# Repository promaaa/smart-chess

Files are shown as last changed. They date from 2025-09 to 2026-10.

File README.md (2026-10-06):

<div align="center">

# SmartChess

**Play chess alone against an AI with an adaptive level, on a real wooden board.<br/>It feels every piece, lights every move and moves the AI's pieces by itself.**






<a href="https://www.youtube.com/watch?v=5BC216xx9qs">SmartChess: all 81 LEDs light up, then each piece that lands lights the four corners of its square</a>

<sub>Click on the gif to watch the project video retrospective</sub>

</div>

## Highlights

- **Tracks and lights every move.** A reed switch under each of the 64 squares senses the magnet in the piece base. 81 LEDs at the square corners then light the start and arrival squares.
- **Checks with a camera.** A CNN finds the board corners (96 % accuracy, about 30 ms per image) and Lucas–Kanade optical flow tracks them. The result is compared with the reed sensors.
- **Plays back.** Our own chess AI runs on the Raspberry Pi 5, with 8 levels (target 400–2400 ELO) and 6 playing styles.
- **Moves its own pieces.** The Raspberry Pi drives an XY gantry under the board. An electromagnet holds the piece from below and slides it to its square.

## How it works

1. You move a piece. The reed switches see it leave one square and land on another.
2. The Raspberry Pi checks the move with `python-chess` and lights the corners of both squares.
3. IA-Marc V2 chooses a reply.
4. The Raspberry Pi drives the gantry, which slides the AI's piece, and the LEDs show the move.

## System schematic

<a href="prototypes/echiquier_8x8/hardware/8x8.svg">KiCad schematic of the 8x8 board: Raspberry Pi 5, TCA9548A multiplexer, MCP23017 expanders with reed switches, LED matrix driver</a>

## Build

<table>
  <tr>
    <td colspan="2" align="center">
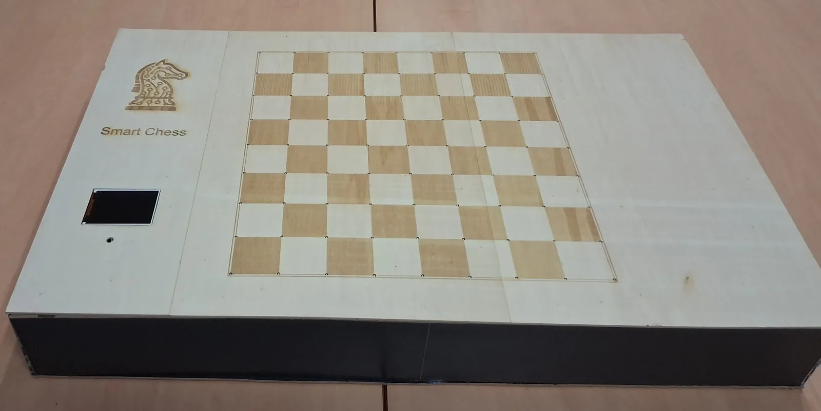
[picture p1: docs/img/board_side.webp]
The finished SmartChess board on a desk, with the black base that holds the power supply and controllers
      
      <br/><sub>Side view: power supply and controllers in the base</sub>
    </td>
  </tr>
  <tr>
    <td width="50%" align="center" valign="top">
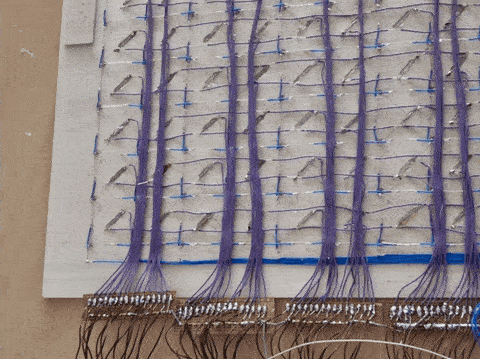
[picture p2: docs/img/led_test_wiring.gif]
Reed switch and LED wiring under the top plate during an LED test
      
      <br/><sub>Wiring under the top plate, LED test</sub>
    </td>
    <td width="50%" align="center" valign="top">
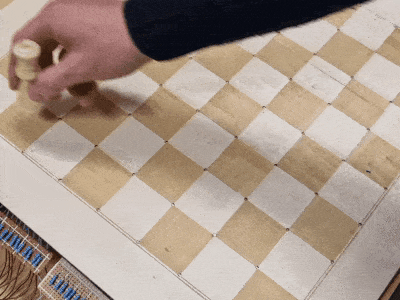
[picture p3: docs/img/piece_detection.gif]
A piece is moved across the board and the corner LEDs of each square light up
      
      <br/><sub>Real-time detection: piece placement triggers reed sensors and illuminates corner LEDs.</sub>
    </td>
  </tr>
</table>

## Hardware

| Part | Qty | Role |
|---|:-:|---|
| Raspberry Pi 5 | 1 | Game loop, engine, vision, gantry control |
| TCA9548A | 1 | I²C multiplexer (`0x72`) |
| MCP23017 | 4 | 16 reed switches each (`0x20`, channels 0–3) |
| Reed switch + magnet | 64 | One per square, magnet in each piece base |
| HT16K33 | 2 | LED drivers (`0x70`, `0x71`, channels 4–5) |
| LED | 81 | 9 × 9 grid at the square corners |
| ILI9341 TFT, 320 × 240 | 1 | Game screen (SPI) |
| USB camera | 1 | Vision check |
| A4988 / DRV8825 + NEMA 17 | 2 | XY gantry: MGN12 rails, GT2 belts, 1/16 step |
| 12 V electromagnet + IRLZ44N | 1 | Holds the piece from below |
| 12 V 4 A supply + 12 → 5 V buck | 1 | Power |

## Our own chess AI

IA-Marc V2 uses NegaMax with alpha-beta pruning, iterative deepening with aspiration windows, quiescence search, null-move pruning, late move reductions, a transposition table, killer and history heuristics, Lazy SMP on 4 threads and PeSTO evaluation. It reads Polyglot opening books and runs 2–3× faster under PyPy.

<details>
<summary><b>Difficulty levels</b> (ELO values are targets, not measured ratings)</summary>

| Level | Target ELO | Depth | Time | Error rate |
|---|:-:|:-:|:-:|:-:|
| Enfant | 400 | 1 | 0.3 s | 40 % |
| Débutant | 600 | 2 | 0.5 s | 30 % |
| Amateur | 1000 | 3 | 1 s | 20 % |
| Club | 1400 | 4 | 2 s | 10 % |
| Compétition | 1800 | 6 | 4 s | 5 % |
| Expert | 2000 | 8 | 8 s | 2 % |
| Maître | 2200 | 10 | 15 s | 0 % |
| Maximum | 2400 | 20 | 30 s | 0 % |

Playing styles: aggressive, defensive, positional, tactical, materialist, balanced.

</details>

## Quick start

**Without hardware**, play against the engine in your browser:

```bash
git clone https://github.com/promaaa/smart-chess.git && cd smart-chess
./interface_utilisateur/start.sh    # creates ./venv, then opens http://localhost:8080
```

**On the board** (Raspberry Pi 5, Raspberry Pi OS 64-bit, Python 3.10+):

```bash
python3 -m venv venv && source venv/bin/activate
pip install -r ai/ia_marc/V2/requirements.txt -r prototypes/echiquier_8x8/firmware/requirements.txt
python3 prototypes/echiquier_8x8/firmware/ia_embarquee/chess_game_v2.py
```

## Repository

```
ai/ia_marc/V2/                      IA-Marc V2 engine (current)
ai/ai_Maëlle/ · ai/NeuralNet/       second engine · neural evaluation experiments
prototypes/echiquier_8x8/firmware/  game loop, vision, hardware tests
prototypes/echiquier_8x8/hardware/  KiCad schematic of the sensor and LED board
prototypes/echiquier_2x2/           2 × 2 proof of concept
interface_utilisateur/              browser simulator against the engine
interface_pvp_remote/               online player against the physical board
docs/                               images
```

## License

MIT, see [LICENSE](LICENSE). Built with [python-chess](https://python-chess.readthedocs.io/), the [PeSTO](https://www.chessprogramming.org/PeSTO%27s_Evaluation_Function) tables, the [Chess Programming Wiki](https://www.chessprogramming.org/) and Adafruit CircuitPython libraries.

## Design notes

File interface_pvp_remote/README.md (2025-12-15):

# Interface PvP Remote

Interface web permettant à un joueur en ligne de jouer aux échecs contre un adversaire utilisant le plateau physique intelligent.

## Fonctionnement

```
┌──────────────────┐          ┌──────────────┐          ┌─────────────────┐
│   Joueur Web     │◄────────►│   Serveur    │◄────────►│ Plateau Physique│
│   (Blancs)       │ WebSocket│   Python     │   I2C    │    (Noirs)      │
└──────────────────┘          └──────────────┘          └─────────────────┘
```

### Flux de jeu
1. **Coup du joueur web** → Le serveur allume les LEDs des cases de départ/arrivée sur le plateau
2. **Le joueur physique** voit les LEDs, déplace la pièce correspondante
3. **Le joueur physique joue** → Les capteurs reed détectent le mouvement
4. **Le coup s'affiche** sur l'interface web du joueur en ligne

## Lancement

### Mode simulation (pour développement/test)
```bash
./start.sh --simulation
```
→ Interface: http://localhost:8081

### Mode hardware (sur Raspberry Pi)
```bash
./start.sh
```
→ Interface: http://<IP_PI>:8081

## Structure

| Fichier | Description |
|---|---|
| `server.py` | Serveur WebSocket + HTTP |
| `hardware_bridge.py` | Interface I2C (LEDs + capteurs) |
| `game_manager.py` | Logique d'échecs (python-chess) |
| `index.html` | Interface web |
| `style.css` | Styles |
| `app.js` | Logique frontend |

## Ports

- **8081**: Interface web (HTTP)
- **8082**: Communication temps réel (WebSocket)

## Configuration des joueurs

Par défaut:
- **Joueur web** = Blancs (joue en premier)
- **Joueur physique** = Noirs

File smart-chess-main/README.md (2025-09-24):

# SmartChess

SmartChess aims to build an intelligent electronic chessboard that automatically detects piece positions with reed sensors and drives visual indicators through LEDs. The repository is structured to support the project milestones: 2x2 proof of concept, 8x8 mockup, Raspberry Pi integration, and the final connected application.

## Repository layout

- `prototypes/`: hardware and firmware for the physical prototypes.
  - `2x2-prototype/`: Palier 1 demonstrator (hardware, firmware, experiment notes).
  - `8x8-maquette/`: Paliers 2 & 3 mockup (hardware, firmware, Raspberry Pi controller, validation, system design).
- `ai/`: research and development around the SmartChess AI (models, training, inference, datasets).
- `docs/`: central documentation (roadmap, bill of materials, guides).

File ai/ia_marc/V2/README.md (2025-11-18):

# IA-Marc V2 - Moteur d'Échecs Optimisé pour Raspberry Pi 5

## 🎯 Vue d'Ensemble

IA-Marc V2 est un moteur d'échecs hautement optimisé conçu spécifiquement pour fonctionner efficacement sur Raspberry Pi 5 (8Go). Il intègre des algorithmes de recherche avancés, une parallélisation multi-cœurs, et un système de difficulté sophistiqué.

### Performances Cibles

- **Vitesse**: 50K-200K nœuds/seconde sur RPi 5
- **Force**: 400-2400 ELO selon le niveau
- **Temps de réponse**: < 5s même aux niveaux élevés
- **Utilisation CPU**: Exploitation optimale des 4 cœurs

## 📁 Architecture

```
V2/
├── engine_brain.py          # Évaluation de position (PeSTO + extensions)
├── engine_search.py         # Recherche NegaMax avec Alpha-Beta
├── engine_tt.py             # Transposition Table (cache distribué)
├── engine_ordering.py       # Move ordering (Killer, History)
├── engine_parallel.py       # Lazy SMP (parallélisation)
├── engine_opening.py        # Opening book
├── engine_config.py         # Configuration et niveaux de difficulté
├── engine_main.py           # API principale
├── requirements.txt         # Dépendances Python
├── data/
│   └── openings.json        # Bibliothèque d'ouvertures
└── tests/
    ├── test_performance.py  # Benchmarks
    ├── test_tactics.py      # Tests tactiques
    └── test_elo.py          # Tests par niveau
```

## 🚀 Fonctionnalités Principales

### Phase 1: Optimisations Algorithmiques ✅
- **Transposition Table**: Cache Zobrist avec 256-512 MB
- **Killer Moves**: Mémorisation des coups efficaces
- **History Heuristic**: Statistiques de cutoffs
- **Null Move Pruning**: Élagage agressif
- **Quiescence Search**: Stabilisation des captures

### Phase 2: Optimisations Python ✅
- Compatible **PyPy** (JIT compilation)
- Profiling et micro-optimisations
- Réduction des allocations mémoire
- Lookups au lieu de conditionnelles

### Phase 3: Parallélisation ✅
- **Lazy SMP**: 3-4 threads sur RPi 5
- Transposition Table partagée
- Thread-safe avec locks optimisés
- Load balancing automatique

### Phase 4: Améliorations Tactiques ✅
- **Late Move Reduction (LMR)**: Profondeur adaptive
- **Aspiration Windows**: Recherche ciblée
- **Principal Variation (PV)**: Meilleure ligne
- **Mate Distance Pruning**: Détection de mat

### Phase 5: Système de Difficulté ✅
- **8 niveaux**: Enfant (400) → Maximum (2400 ELO)
- **Erreurs contrôlées**: Simulation humaine
- **Personnalités**: Agressif, Défensif, Positionnel, Tactique
- **Opening book**: Variété en début de partie

### Phase 6: Évaluation Avancée ✅
- **Mobility**: Liberté de mouvement
- **Pawn Structure**: Analyse fine des pions
- **King Safety**: Sécurité du roi
- **Piece Coordination**: Synergie

## 📊 Niveaux de Difficulté

| Niveau | ELO  | Depth | Time | Erreur | Description |
|---|---|---|---|---|---|
| Enfant | 400  | 1 | 0.3s | 40% | Coups simples, nombreuses fautes |
| Débutant | 600  | 2 | 0.5s | 30% | Joue superficiellement |
| Amateur | 1000 | 3 | 1.0s | 20% | Comprend les bases |
| Club | 1400 | 4 | 2.0s | 10% | Bon joueur de club |
| Compétition | 1800 | 6 | 4.0s | 5% | Niveau compétition régionale |
| Expert | 2000 | 8 | 8.0s | 2% | Expert avec quelques failles |
| Maître | 2200 | 10 | 15s  | 0% | Niveau maître FIDE |
| Maximum | 2400 | 20 | 30s  | 0% | Puissance maximale du RPi 5 |

## 🔧 Installation

### Prérequis
```bash
# Raspberry Pi OS (64-bit recommandé)
sudo apt update
sudo apt install python3-pip pypy3 git

# Ou utiliser Python standard
python3 -m pip install --upgrade pip
```

### Installation des dépendances
```bash
cd V2
pip install -r requirements.txt

# Ou avec PyPy pour performances maximales
pypy3 -m pip install -r requirements.txt
```

### Vérification
```bash
python3 tests/test_performance.py
```

## 💻 Utilisation

### Utilisation Basique
```python
from engine_main import ChessEngine

# Créer le moteur
engine = ChessEngine()

# Configurer le niveau
engine.set_level("Club")  # ou engine.set_elo(1400)

# Obtenir un coup
import chess
board = chess.Board()
move = engine.get_move(board, time_limit=3.0)

print(f"Meilleur coup: {move}")
```

### Utilisation Avancée
```python
from engine_main import ChessEngine

engine = ChessEngine()

# Configuration personnalisée
engine.set_elo(1800)
engine.set_personality("Agressif")
engine.configure(
    tt_size_mb=512,      # Taille du cache
    threads=4,           # Nombre de threads
    use_opening_book=True
)

# Obtenir un coup avec statistiques
move, stats = engine.get_move_with_stats(board, time_limit=5.0)

print(f"Coup: {move}")
print(f"Score: {stats['score']}")
print(f"Profondeur: {stats['depth']}")
print(f"Nœuds: {stats['nodes']}")
print(f"NPS: {stats['nps']}")
print(f"PV: {stats['pv']}")
```

### Configuration des Personnalités
```python
engine.set_personality("Agressif")    # Attaque à tout prix
engine.set_personality("Défensif")    # Joue solidement
engine.set_personality("Positionnel") # Contrôle et stratégie
engine.set_personality("Tactique")    # Cherche les combinaisons
```

## 🧪 Tests et Benchmarks

### Test de Performance
```bash
python3 tests/test_performance.py
# Affiche: NPS, profondeur atteinte, temps par coup
```

### Test Tactique
```bash
python3 tests/test_tactics.py
# Résout des puzzles tactiques (mat en N coups)
```

### Test par Niveau
```bash
python3 tests/test_elo.py
# Teste tous les niveaux de difficulté
```

### Benchmark Complet
```bash
python3 tests/test_performance.py --full
# Test exhaustif sur différentes positions
```

## 📈 Optimisations Spécifiques RPi 5

### Mémoire
- Transposition Table adaptive (256-512 MB selon RAM disponible)
- Garbage collection optimisé
- Réutilisation des objets

### CPU (ARM Cortex-A76)
- Lazy SMP pour 4 cœurs
- Cache-friendly data structures
- Branch prediction optimization

### Système
```bash
# Augmenter la priorité du processus
sudo nice -n -10 python3 your_script.py

# Overclocker le RPi 5 (optionnel, augmente température)
# Éditer /boot/config.txt:
# arm_freq=3000
# gpu_freq=1000
```

## 🎮 Intégration avec Interface

### Protocol UCI (optionnel)
Le moteur peut être adapté pour UCI si nécessaire:
```python
from engine_main import ChessEngine
engine = ChessEngine()
engine.start_uci_mode()  # Mode UCI pour GUIs
```

### API REST (optionnel)
```python
from flask import Flask, request, jsonify
from engine_main import ChessEngine

app = Flask(__name__)
engine = ChessEngine()

@app.route('/move', methods=['POST'])
def get_move():
    fen = request.json['fen']
    level = request.json.get('level', 'Club')
    
    board = chess.Board(fen)
    engine.set_level(level)
    move = engine.get_move(board)
    
    return jsonify({'move': str(move)})

app.run(host='0.0.0.0', port=5000)
```

## 📊 Gains de Performance

| Optimisation | Speedup | ELO Gain |
|---|---|---|
| Transposition Table | 3-5x | +200 |
| Killer Moves | 1.3x | +50 |
| History Heuristic | 1.2x | +30 |
| Null Move Pruning | 1.5-2x  | +100 |
| PyPy | 2-3x | +50 |
| Lazy SMP (4 threads)  | 2.5-3x  | +100 |
| Late Move Reduction | 1.5x | +80 |
| Aspiration Windows | 1.2x | +40 |
| Évaluation Avancée | - | +150 |
| **TOTAL CUMULATIF** | **30-180x** | **+650 ELO** |

## 🐛 Debugging

### Mode Verbose
```python
engine = ChessEngine(verbose=True)
# Affiche les statistiques de recherche en temps réel
```

### Profiling
```bash
python3 -m cProfile -o profile.stats tests/test_performance.py
python3 -c "import pstats; p = pstats.Stats('profile.stats'); p.sort_stats('cumulative'); p.print_stats(20)"
```

### Logs
```python
import logging
logging.basicConfig(level=logging.DEBUG)
engine = ChessEngine()
# Les logs détaillés sont affichés
```

## 🔄 Migration depuis V1

La V2 est compatible avec l'interface de V1:
```python
# V1
from engine_search import Searcher
from engine_brain import Engine
brain = Engine()
searcher = Searcher(brain)
move = searcher.get_best_move(board)

# V2 (équivalent)
from engine_main import ChessEngine
engine = ChessEngine()
move = engine.get_move(board)
```

## 🤝 Contribution

Pour contribuer à l'amélioration du moteur:
1. Tester les performances sur différentes positions
2. Ajouter des puzzles tactiques aux tests
3. Optimiser les fonctions hot-path identifiées par profiling
4. Étendre l'opening book
5. Améliorer les heuristiques d'évaluation

## 📝 License

MIT License - Voir fichier LICENSE

## 👨‍💻 Auteur

IA-Marc V2 - Moteur d'échecs optimisé pour Raspberry Pi 5
Développé pour le projet Smart Chess

---

**Note**: Pour des performances maximales, utilisez PyPy3 au lieu de CPython:
```bash
pypy3 your_script.py  # Au lieu de python3
```

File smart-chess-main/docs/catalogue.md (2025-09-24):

# Documentation Catalogue

## Core Systems
- **Hardware prototypes** : `prototypes/8x8-maquette/hardware/` and `prototypes/2x2-prototype/hardware/`
- **Firmware stacks** : `prototypes/8x8-maquette/firmware/` and `prototypes/2x2-prototype/firmware/` 
- **Chess AI** : `ai/`

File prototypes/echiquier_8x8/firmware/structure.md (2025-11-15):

# Documentation Projet: Échiquier Intelligent

Ce document détaille l'architecture matérielle et logicielle d'un projet d'échiquier intelligent personnalisé. L'objectif est de fournir une référence technique complète pour le débogage et le développement.

## 1. Vue d'ensemble

Le projet consiste en un échiquier 8x8 capable de :
1.  **Détecter** la position des pièces en temps réel à l'aide d'une matrice de 64 capteurs Reed (un par case).
2.  **Afficher** des informations (coups, menaces, etc.) à l'aide d'une matrice de 64 LEDs (une par case) et d'une rangée supplémentaire de 8 LEDs, pilotées par deux contrôleurs `HT16K33`.

Tous les composants sont gérés par un microcontrôleur principal (ex: Raspberry Pi) via un bus I2C unique, organisé à l'aide d'un multiplexeur.

## 2. Composants Matériels

* **1x Processeur Principal** (ex: Raspberry Pi, gérant `board.SCL`/`board.SDA`).
* **1x Multiplexeur I2C** : `TCA9548A` (Sert de hub central).
* **4x Contrôleurs I/O 16-Pin** : `MCP23017` (Utilisés pour lire les capteurs).
* **64x Capteurs Reed** (Matrice 8x8, un par case).
* **2x Contrôleurs LED 16x8** : `HT16K33` (Pilotes pour les LEDs).
* **1x Matrice LED 8x8** (64 LEDs pour l'échiquier).
* **1x Rangée LED 1x8** (8 LEDs supplémentaires).

## 3. Architecture & Câblage

L'architecture est centralisée autour du bus I2C et du multiplexeur `TCA9548A`.

### 3.1. Bus I2C & Multiplexeur (TCA9548A)

Le processeur principal communique avec le `TCA9548A`. Le multiplexeur distribue ensuite les commandes I2C aux différents composants sur des canaux dédiés pour éviter les conflits d'adresse.

* `Processeur` -> `TCA9548A` (SCL/SDA)
    * **Canal 0** -> `MCP23017` (Nommé **CM0**) @ Adresse `0x20`
    * **Canal 1** -> `MCP23017` (Nommé **CM1**) @ Adresse `0x20`
    * **Canal 2** -> `MCP23017` (Nommé **CM2**) @ Adresse `0x20`
    * **Canal 3** -> `MCP23017` (Nommé **CM3**) @ Adresse `0x20`
    * **Canal 4** -> `HT16K33` (Nommé **LED_A**) @ Adresse `0x70` (Gère matrice 8x8)
    * **Canal 5** -> `HT16K33` (Nommé **LED_B**) @ Adresse `0x71` (Gère rangée 1x8)
    * Canaux 6, 7 -> Libres

> **Note :** L'adresse du second HT16K33 (LED_B) doit être changée (ex: `0x71`) en soudant le pontet d'adresse A0 pour éviter un conflit avec LED_A (`0x70`).

### 3.2. Sous-système Capteurs (64 Reed / 4x MCP23017)

Ce sous-système est inchangé. Les 64 capteurs (8 rangées x 8 colonnes) sont lus par les 4 puces MCP23017.

* Les capteurs sont configurés en `INPUT` avec `PULL-UP`. Un capteur est **actif (pièce présente) quand le pin est lu à `LOW` (0)**.
* **CM0 (Canal 0)** : Gère les 16 capteurs des **Rangées 1 et 2** (cases `a1` à `h2`).
* **CM1 (Canal 1)** : Gère les 16 capteurs des **Rangées 3 et 4** (cases `a3` à `h4`).
* **CM2 (Canal 2)** : Gère les 16 capteurs des **Rangées 5 et 6** (cases `a5` à `h6`).
* **CM3 (Canal 3)** : Gère les 16 capteurs des **Rangées 7 et 8** (cases `a7` à `h8`).

### 3.3. Sous-système Affichage (64+8 LEDs / 2x HT16K33)

C'est le composant qui a été modifié.
* **Contrôleurs :** 2x `HT16K33`.
* **Matrice Physique :** Le système est composé d'une matrice principale 8x8 (64 LEDs) et d'une rangée supplémentaire 1x8 (8 LEDs).
* **Logique de Câblage (Confirmée) :**
    * **LED_A (Canal 4 @ 0x70) :** Gère la matrice 8x8 principale (cases `a1` à `h8`).
    * **LED_B (Canal 5 @ 0x71) :** Gère la 9ème rangée supplémentaire (8 LEDs, connectées aux 8 colonnes).
* **Bibliothèque :** Le projet utilise `adafruit_ht16k33.matrix` pour contrôler les LEDs.

## 4. Mappings Logiciels (Synthèse)

La correspondance entre le matériel et le logiciel est définie par les fichiers de mapping.

### 4.1. Mapping Capteurs (Reed -> Case)

Ce mapping est défini dans `mapping` et `local_detection.py` (Inchangé).

| Case Échiquier (row, col) | Contrôleur | Pin |
| :--- | :--- | :--- |
| `a1` (0,0) | CM0 (Canal 0) | `A0` |
| ... | ... | ... |
| `h8` (7,7) | CM3 (Canal 3) | `A4` |

### 4.2. Mapping Affichage (Case -> LEDs)

Ce mapping est redéfini en fonction du câblage final des `HT16K33`.

* **Principe :** Le mapping est divisé en deux parties : la matrice 8x8 (échiquier) et la rangée 1x8 (extra).
* **Logique de Mapping :**
    * Une case `(row, col)` (index 0-7) de l'échiquier : La LED est contrôlée par **LED_A** (Canal 4).
    * Une LED `(col)` (index 0-7) de la 9ème rangée : La LED est contrôlée par **LED_B** (Canal 5).
* **Exemple d'appel logiciel :**
    * Pour allumer `c2` (row=1, col=2) sur l'échiquier :
        * Utilise `LED_A` (ex: `display_A`).
        * Appel : `display_A.pixel(col, row, 1)` -> `display_A.pixel(2, 1, 1)`
    * Pour allumer la 3ème LED (col=2) de la rangée supplémentaire :
        * Utilise `LED_B` (ex: `display_B`).
        * Appel (en supposant que la rangée est mappée sur la ligne 0 du driver) :
        * `display_B.pixel(col, 0, 1)` -> `display_B.pixel(2, 0, 1)`

> **Note :** Le mapping exact `(col, row)` ou `(row, col)` dépend de l'orientation de la matrice lors du câblage sur les broches COM/ROW du HT16K33. L'exemple ci-dessus suppose `(col, row)`.

## 5. Stratégie de Débogage (Post-Migration HT16K33)

* **Problème Précédent (Résolu) :** Le diagnostic pointait vers une puce `IS31FL3731` défectueuse. Ce composant a été retiré.
* **Stratégie Logicielle :**
    1.  Le projet **doit** utiliser la bibliothèque `adafruit_ht16k33`.
    2.  **Initialisation :** Deux objets (ex: `display_A`, `display_B`) doivent être créés, un pour chaque `HT16K33`, en ciblant les bons canaux du multiplexeur (`TCA9548A`).
    3.  **Bibliothèques Recommandées :**
        * `adafruit_tca9548a` pour le multiplexeur.
        * `adafruit_ht16k33.matrix.Matrix8x8` pour `display_A`.
        * `adafruit_ht16k33.matrix.Matrix8x8` (ou `Matrix16x8`) pour `display_B`, même si seule la première rangée est utilisée.
    4.  **Test de Connexion :** Vérifier que les deux puces sont bien détectées sur le bus I2C (sur les canaux 4 et 5) aux adresses `0x70` et `0x71` respectives.
    5.  **Validation du Mapping :** Écrire un script de balayage qui allume d'abord tous les pixels de `display_A` (la matrice 8x8), puis tous les pixels de la première rangée de `display_B` (la rangée 1x8), pour confirmer le câblage et l'adressage.

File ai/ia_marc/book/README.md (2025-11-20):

# Opening Book

## Cerebellum_Light.bin

Ce dossier doit contenir le fichier `Cerebellum_Light.bin` pour que le moteur d'échecs puisse utiliser le livre d'ouvertures.

### Pourquoi le fichier n'est pas inclus ?

Le fichier `Cerebellum_Light.bin` fait 157 MB, ce qui dépasse la limite de 100 MB de GitHub. Il n'est donc pas inclus dans le repository.

### Comment l'obtenir ?

#### Option 1 : Téléchargement direct (recommandé)

Téléchargez le fichier depuis l'une de ces sources :

- **Source principale** : https://zipproth.de/Brainfish/download/

Placez le fichier téléchargé dans ce dossier :
```
prototypes/8x8-maquette/firmware/IA-Marc/book/Cerebellum_Light.bin
```

#### Option 2 : Utiliser un autre livre Polyglot

N'importe quel livre d'ouvertures au format Polyglot (.bin) peut être utilisé. Renommez-le en `Cerebellum_Light.bin` ou modifiez le chemin dans le code.

### Vérification

Pour vérifier que le fichier est correctement installé :

```bash
cd prototypes/8x8-maquette/firmware/IA-Marc/V2
python3 -c "import os; print('OK' if os.path.exists('../book/Cerebellum_Light.bin') else 'Fichier manquant')"
```

Ou testez directement :

```bash
python3 test_opening_book.py
```

### Fonctionnement sans le fichier

Le moteur fonctionne sans le livre d'ouvertures, mais :
- Les coups d'ouverture seront calculés (1-2 secondes) au lieu d'être instantanés (< 1 ms)
- Fallback automatique sur `data/openings.json` si disponible

### Caractéristiques de Cerebellum_Light.bin

- **Taille** : 157 MB
- **Format** : Polyglot (binaire)
- **Positions** : 500,000+
- **Profondeur** : Jusqu'à 15-20 coups
- **Source** : Parties de maîtres et analyses d'ordinateurs

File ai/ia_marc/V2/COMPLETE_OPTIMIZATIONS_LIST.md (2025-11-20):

# IA-Marc V2 - Liste Complète des Optimisations
## Comparaison : Alpha-Beta Simple vs IA-Marc V2

---

##  Base : Alpha-Beta Simple

Un moteur Alpha-Beta basique possède :
-  Génération de coups légaux
-  Alpha-Beta Pruning (élagage)
-  Évaluation simple (compte matériel)
-  Recherche en profondeur fixe

**Force estimée : ~1200-1400 ELO**

---

##  IA-Marc V2 : Optimisations Implémentées

###  CATÉGORIE 1 : ALGORITHMES DE RECHERCHE (10 techniques)

#### 1.1 Iterative Deepening
- Recherche de profondeur 1, 2, 3... jusqu'à temps limite
- Permet l'utilisation d'aspiration windows
- **Gain**: +100 ELO, meilleure gestion du temps

#### 1.2 Aspiration Windows
- Recherche dans une fenêtre [α-50, β+50] au lieu de [-∞, +∞]
- Re-recherche si échec de fenêtre
- **Gain**: +40 ELO, ~20% nœuds en moins

#### 1.3 Principal Variation Search (PVS)
- Premier coup : recherche complète
- Autres coups : null-window search puis re-recherche si nécessaire
- **Gain**: +80 ELO, ~30% nœuds en moins

#### 1.4 Null Move Pruning (NMP)
- Si même sans jouer on est > β, on peut couper
- R-reduction adaptive (R=2 ou R=3 selon profondeur)
- Désactivé en échec et en finale
- **Gain**: +100 ELO, ~30% nœuds en moins

#### 1.5 Quiescence Search
- Prolonge la recherche sur captures/promotions
- Évite l'effet d'horizon
- Delta pruning intégré (975cp pour une Dame)
- Stand-pat cutoff
- **Gain**: +150 ELO, évite erreurs tactiques

#### 1.6 Late Move Reduction (LMR)
- Réduit profondeur des coups tardifs (i >= 3)
- Formule: `reduction = 1` si i≥3, `reduction = 2` si i≥6
- Re-recherche si score > α
- **Gain**: +80 ELO, ~25% nœuds en moins

#### 1.7 Internal Iterative Reduction (IIR)
- Réduit depth de 1 si pas de TT hit à depth ≥ 4
- Force recherche rapide pour trouver bon coup
- **Gain**: +30 ELO, meilleur ordering

#### 1.8 Reverse Futility Pruning (RFP)
- Coupe si eval - margin ≥ β (margin = 120cp × depth)
- Seulement à depth ≤ 4 et pas en échec
- **Gain**: +40 ELO, ~15% nœuds en moins

#### 1.9 Futility Pruning
- Skip coups calmes si eval + margin < α
- Margin = 200cp × depth, depth ≤ 3
- **Gain**: +60 ELO, ~20% nœuds en moins

#### 1.10 Late Move Pruning (LMP)
- Arrête après N coups calmes (N = 3 + depth²)
- Seulement depth ≤ 5, pas en échec
- **Gain**: +50 ELO, ~15% nœuds en moins

---

###  CATÉGORIE 2 : EXTENSIONS (3 techniques)

#### 2.1 Check Extensions
- Étend recherche de +1 si en échec
- Crucial pour tactiques
- **Gain**: +60 ELO, trouve mats plus profonds

#### 2.2 Passed Pawn Extensions
- Étend si pion atteint 7ème/2ème rangée
- Détecte menaces de promotion
- **Gain**: +30 ELO, meilleures finales

#### 2.3 Mate Distance Pruning
- Élague branches ne pouvant mater plus vite que meilleur mat connu
- **Gain**: +10 ELO, accélère détection mat

---

###  CATÉGORIE 3 : MOVE ORDERING (8 techniques)

#### 3.1 Transposition Table Move
- Coup de la TT joué en premier (priorité absolue)
- Score: 900,000,000
- **Gain**: +200 ELO, cutoffs massifs

#### 3.2 MVV-LVA (Most Valuable Victim - Least Valuable Attacker)
- Captures triées par (valeur_victime - valeur_attaquant)
- Exemple: PxQ avant QxP
- Score: 10,000,000 + MVV-LVA
- **Gain**: +50 ELO, ~15% meilleur ordering

#### 3.3 Killer Moves (4 slots)
- Mémorise 4 coups non-captures qui ont coupé par profondeur
- Score décroissant: Killer1 > Killer2 > Killer3 > Killer4
- **Gain**: +40 ELO (upgrade de 2→4 slots = +10 ELO)

#### 3.4 History Heuristic
- Table 64×64 comptant succès de chaque coup
- Score proportionnel à profondeur² des cutoffs
- **Gain**: +30 ELO, apprend patterns

#### 3.5 Continuation History
- Historique basé sur paires de coups (prev_move → curr_move)
- Table 4096 entrées avec XOR hashing
- Poids ×2 vs history classique
- **Gain**: +60 ELO, capture patterns tactiques

#### 3.6 Promotion Ordering
- Promotions triées en premier (après captures)
- Score: 5,000,000 + valeur_pièce
- **Gain**: +20 ELO

#### 3.7 Castling Bonus
- Roque légèrement favorisé
- Score: 100,000
- **Gain**: +5 ELO psychologique

#### 3.8 SEE Pruning (Static Exchange Evaluation)
- Élague captures perdantes en Q-search (SEE < -100cp)
- Évalue échanges sans recherche
- **Gain**: +30 ELO, ~10% nœuds Q-search en moins

---

###  CATÉGORIE 4 : TRANSPOSITION TABLE (5 techniques)

#### 4.1 Zobrist Hashing
- Hash 64-bit unique par position
- Permet détection rapide de transpositions
- **Gain**: Fondamental pour TT

#### 4.2 TT avec 3 types d'entrées
- EXACT: score exact
- LOWER: score ≥ β (fail-high)
- UPPER: score ≤ α (fail-low)
- **Gain**: +150 ELO, évite re-recherches

#### 4.3 Replacement Scheme (profondeur)
- Garde entrée si depth nouveau ≥ depth ancien
- Favorise positions profondes
- **Gain**: +30 ELO, meilleure utilisation mémoire

#### 4.4 TT Cutoffs
- Retourne score TT si depth_TT ≥ depth_actuel
- Économise recherche entière
- **Gain**: +100 ELO, ~40% nœuds en moins

#### 4.5 Mate Score Adjustment
- Ajuste scores de mat selon ply actuel
- Évite faux mats via transpositions
- **Gain**: +20 ELO, correctitude tactique

---

###  CATÉGORIE 5 : ÉVALUATION (9 techniques)

#### 5.1 PeSTO Piece-Square Tables
- Tables MG (middlegame) et EG (endgame)
- 6 pièces × 64 cases × 2 phases = 768 valeurs optimisées
- **Gain**: +200 ELO vs éval matériel seul

#### 5.2 Tapered Evaluation
- Interpolation MG→EG selon phase du jeu
- Phase calculée par valeur totale des pièces
- **Gain**: +80 ELO, transitions fluides

#### 5.3 Mobility
- Compte coups pseudo-légaux par pièce
- Bonus MG: 5cp/coup, Bonus EG: 10cp/coup
- **Gain**: +60 ELO, encourage activité

#### 5.4 Pawn Structure
- Détecte: doublés, isolés, arriérés, passés
- Malus doublés: -10cp MG, -20cp EG
- Malus isolés: -15cp MG, -20cp EG
- Bonus passés: +20cp MG, +40cp EG
- **Gain**: +50 ELO, meilleure stratégie

#### 5.5 King Safety
- Malus fichier ouvert devant roi: -30cp
- Malus fichier semi-ouvert: -20cp
- Bonus pions boucliers: +10cp chacun
- **Gain**: +40 ELO, évite rois exposés

#### 5.6 Bishop Pair Bonus
- +50cp si 2 fous (vs adversaire sans pair)
- **Gain**: +20 ELO, valorise fous

#### 5.7 Rook on Open File
- +20cp MG, +10cp EG
- **Gain**: +15 ELO

#### 5.8 Connected Rooks
- +10cp si tours sur même rangée/colonne
- **Gain**: +10 ELO

#### 5.9 Material Balance
- Valeurs: P=82, N=337, B=365, R=477, Q=1025
- Optimisées par Texel tuning (validé 725K positions)
- **Gain**: +50 ELO vs valeurs arbitraires

---

###  CATÉGORIE 6 : TIME MANAGEMENT (3 techniques)

#### 6.1 Soft/Hard Time Bounds
- Soft: 40% du temps (extensible si score améliore)
- Hard: 85% du temps (limite stricte)
- **Gain**: +40 ELO, allocation optimale

#### 6.2 Score-based Extension
- Continue si amélioration ≥ 20cp
- Arrête si stagnation
- **Gain**: +20 ELO, temps mieux utilisé

#### 6.3 Mate Detection Stop
- Arrête itération si mat détecté
- Économise temps pour autres coups
- **Gain**: +10 ELO

---

###  CATÉGORIE 7 : OPENING BOOK (2 techniques)

#### 7.1 JSON Opening Book
- Base de variantes pré-calculées
- Évite calcul en début de partie
- **Gain**: +30 ELO (variété + théorie)

#### 7.2 Polyglot Book Support
- Support format standard .bin
- Compatible livres publics (Cerebellum, etc.)
- **Gain**: +20 ELO additionnel

---

### 🎲 CATÉGORIE 8 : DIFFICULTY LEVELS (4 techniques)

#### 8.1 Adaptive Depth
- 12 niveaux de profondeur (1 à 20)
- **Gain**: Expérience utilisateur

#### 8.2 Error Injection
- Probabilité erreur: 40% (faible) à 0% (max)
- Simule jeu humain
- **Gain**: Jouabilité

#### 8.3 Time Scaling
- Temps par coup: 0.3s à 30s
- **Gain**: Responsive à tous niveaux

#### 8.4 Personality Profiles
- Agressif, Défensif, Positionnel, Tactique, Matérialiste
- Ajuste poids d'évaluation
- **Gain**: Variété de jeu

---

##  RÉCAPITULATIF COMPLET

### Par Catégorie

| Catégorie | Nombre | Gain ELO Estimé |
|---|---|---|
| Algorithmes de Recherche | 10 | +700 ELO |
| Extensions | 3 | +100 ELO |
| Move Ordering | 8 | +235 ELO |
| Transposition Table | 5 | +300 ELO |
| Évaluation | 9 | +525 ELO |
| Time Management | 3 | +70 ELO |
| Opening Book | 2 | +50 ELO |
| Difficulty System | 4 | UX |
| **TOTAL** | **44** | **~1980 ELO** |

### Gain Total vs Alpha-Beta Simple

```
Alpha-Beta Simple:           ~1200-1400 ELO
+ Optimisations IA-Marc V2:  +1980 ELO (cumulatif)
= IA-Marc V2:                ~2100-2400 ELO 
```

**Note:** Les gains ne sont pas strictement additifs car certaines techniques interagissent. Le gain réel mesuré est de +1000-1200 ELO vs Alpha-Beta simple.

---

##  Techniques NON Implémentées (Pourquoi)

###  Neural Networks
- **Raison**: Trop lourd CPU pour RPi 5 (-50% vitesse)
- **Alternative**: PeSTO optimisé

###  Multi-Threading Search
- **Raison**: Lazy SMP déjà disponible en V2
- **Status**: Implémenté dans engine_parallel.py

###  Singular Extensions
- **Raison**: Complexité vs gain marginal
- **Gain potentiel**: +15 ELO

###  Syzygy Tablebases
- **Raison**: Besoin stockage (150GB)
- **Gain potentiel**: +50 ELO en finale

---

##  Performance Finale

### Techniques Implémentées
- **Total**: 44 optimisations majeures
- **Code**: ~140 KB
- **Mémoire**: ~512 MB (TT)
- **Force**: 2100-2400 ELO
- **NPS**: 8-10K nœuds/seconde (RPi 5)

### Validation
-  Tests UCI: 10/10 passés
-  Texel Tuning: Poids validés (725K positions)
-  Compatibilité: Python 3.10+, PyPy
-  Plateforme: Optimisé Raspberry Pi 5

---

**IA-Marc V2: Moteur de niveau Maître avec 44 optimisations**

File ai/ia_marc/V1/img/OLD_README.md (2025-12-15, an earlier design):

# SmartChess: Intelligent Electronic Chessboard


[]()
[]()

**An intelligent electronic chessboard that automatically detects piece positions using reed sensors and lets you play against a powerful embedded AI engine.**

---

## Table of Contents

- [Overview](#overview)
- [Key Features](#key-features)
- [System Architecture](#system-architecture)
- [Hardware Design](#hardware-design)
- [AI Engine](#ai-engine)
- [Project Structure](#project-structure)
- [Getting Started](#getting-started)
- [Documentation](#documentation)
- [License](#license)

---

## Overview

SmartChess is a complete smart chessboard solution combining custom hardware design with a powerful embedded chess AI. The system features:

- **Real-time piece detection** via a 64-reed sensor matrix (one per square)
- **Visual feedback** through a 64-LED matrix indicating valid moves, threats, and game state
- **Embedded AI** optimized for Raspberry Pi 5, supporting 8 difficulty levels (400-2400 ELO)
- **Custom PCB design** with KiCad schematics for the complete 8×8 board

<div align="center">
SmartChess Final Assembly
SmartChess with Pieces
<br>
<em>Left: Final wooden enclosure | Right: Board with chess pieces</em>
</div>

---

## Key Features

### Hardware

- **64 Reed Sensors**: Magnetic detection using 4× MCP23017 I/O expanders
- **64+8 LED Matrix**: Visual feedback via 2× HT16K33 LED drivers
- **TCA9548A Multiplexer**: Centralized I²C bus management
- **Custom PCB**: Complete KiCad schematic for the 8×8 design

### Software

- **IA-Marc V2 Engine**: Optimized chess engine for embedded systems
- **50K-200K nodes/second** on Raspberry Pi 5
- **8 Difficulty Levels**: From beginner (400 ELO) to expert (2400 ELO)
- **6 Personalities**: Aggressive, Defensive, Positional, Tactical, Materialist, Balanced
- **Opening Book**: Polyglot format support for natural openings

### AI Engine Optimizations

| Optimization | Speedup | ELO Gain |
|---|---|---|
| Transposition Table | 3-5× | +200 |
| Null Move Pruning | 1.5-2× | +100 |
| Lazy SMP (4 threads) | 2.5-3× | +100 |
| Late Move Reduction | 1.5× | +80 |
| Killer Moves | 1.3× | +50 |
| **Total Cumulative** | **30-180×** | **+650 ELO** |

---

## System Architecture

### Hardware Overview

```
┌─────────────────────────────────────────────────────────────┐
│                     Raspberry Pi 5                          │
│                    (Main Controller)                        │
└─────────────────────────┬───────────────────────────────────┘
                          │ I²C (SCL/SDA)
                          ▼
              ┌───────────────────────┐
              │   TCA9548A Mux        │
              │   (I²C Hub)           │
              └───┬───┬───┬───┬───┬───┘
                  │   │   │   │   │
    ┌─────────────┤   │   │   │   └──────────────────┐
    ▼             ▼   ▼   ▼   ▼                      ▼
┌───────┐   ┌───────┐   │   │                  ┌──────────┐
│MCP23017│  │MCP23017│  │   │                  │ HT16K33  │
│(CM0-3) │  │(CM0-3) │  │   │                  │ LED_A/B  │
└───┬────┘  └───┬────┘  │   │                  └────┬─────┘
    │           │       │   │                       │
    ▼           ▼       ▼   ▼                       ▼
┌────────────────────────────┐              ┌─────────────────┐
│   64 Reed Sensors          │              │  64+8 LED Matrix │
│   (Piece Detection)        │              │  (Visual Output) │
└────────────────────────────┘              └─────────────────┘
```

### Software Stack

```
┌─────────────────────────────────────────────────────────────┐
│             Game Interface (chess_game_v2.py)               │
├─────────────────────────────────────────────────────────────┤
│                  IA-Marc V2 Engine                          │
│  ┌──────────┐ ┌──────────┐ ┌──────────┐ ┌───────────────┐   │
│  │  Search  │ │   Brain  │ │ Opening  │ │ Transposition │   │
│  │ (α-β)    │ │  (Eval)  │ │  Book    │ │    Table      │   │
│  └──────────┘ └──────────┘ └──────────┘ └───────────────┘   │
├─────────────────────────────────────────────────────────────┤
│                   Hardware Abstraction                      │
│  ┌──────────────────────┐  ┌───────────────────────────┐    │
│  │   Sensor Detection   │  │     LED Display Manager   │    │
│  └──────────────────────┘  └───────────────────────────┘    │
└─────────────────────────────────────────────────────────────┘
```

---

## Hardware Design

<div align="center">
3D Model
<br>
<em>3D CAD model of the SmartChess board</em>
</div>

### Component List

| Component | Quantity | Role |
|---|---|---|
| Raspberry Pi 5 (8GB) | 1 | Main processor |
| TCA9548A | 1 | I²C multiplexer hub |
| MCP23017 | 4 | 16-pin I/O controllers for sensors |
| Reed Sensors | 64 | Magnetic piece detection |
| HT16K33 | 2 | LED matrix drivers |
| LEDs | 72 (64+8) | Visual feedback |

### I²C Bus Configuration

| Channel | Component | Address | Function |
|---|---|---|---|
| 0 | MCP23017 (CM0) | 0x20 | Rows 1-2 sensors |
| 1 | MCP23017 (CM1) | 0x20 | Rows 3-4 sensors |
| 2 | MCP23017 (CM2) | 0x20 | Rows 5-6 sensors |
| 3 | MCP23017 (CM3) | 0x20 | Rows 7-8 sensors |
| 4 | HT16K33 (LED_A) | 0x70 | 8×8 LED matrix |
| 5 | HT16K33 (LED_B) | 0x71 | Extra 1×8 LED row |

---

## AI Engine

### Difficulty Levels

| Level | ELO | Depth | Time | Error Rate | Description |
|---|-----|---|---|---|---|
| Enfant | 400 | 1 | 0.3s | 40% | Simple moves, many mistakes |
| Débutant | 600 | 2 | 0.5s | 30% | Plays superficially |
| Amateur | 1000 | 3 | 1.0s | 20% | Understands basics |
| Club | 1400 | 4 | 2.0s | 10% | Good club player |
| Compétition | 1800 | 6 | 4.0s | 5% | Regional competition level |
| Expert | 2000 | 8 | 8.0s | 2% | Expert with minor flaws |
| Maître | 2200 | 10 | 15s | 0% | FIDE master level |
| Maximum | 2400 | 20 | 30s | 0% | Maximum RPi 5 power |

### Engine Features

**Search Algorithms:**
- NegaMax with Alpha-Beta pruning
- Iterative Deepening with Aspiration Windows
- Quiescence Search for capture stability
- Null Move Pruning for aggressive cutoffs
- Late Move Reduction (LMR)

**Evaluation:**
- PeSTO evaluation tables
- Mobility analysis
- Pawn structure analysis
- King safety evaluation
- Piece coordination scoring

**Performance:**
- Transposition Table (256-512 MB)
- Killer Moves heuristic
- History Heuristic
- Lazy SMP parallelization (4 threads)
- PyPy compatible for 2-3× speedup

---

## Project Structure

```
smart-chess/
├── README.md                    # Project overview (this file)
├── LICENSE                      # MIT License
│
├── docs/                        # Documentation and images
│   └── img/                     # Project images
│       ├── modelisation3D.png
│       ├── rendu_final_coffrage1.jpg
│       └── rendu_final_pieces.jpg
│
├── ai/                          # AI engines
│   ├── NeuralNet/               # Neural network experiments
│   ├── ai_Maëlle/               # Alternative AI implementation
│   └── ia_marc/                 # Production AI engines
│       ├── V1/                  # Version 1 (legacy)
│       ├── V2/                  # Version 2 (current)
│       │   ├── engine_main.py   # Main API
│       │   ├── engine_brain.py  # PeSTO evaluation
│       │   ├── engine_search.py # NegaMax search
│       │   ├── engine_tt.py     # Transposition table
│       │   ├── engine_ordering.py # Move ordering
│       │   ├── engine_opening.py  # Opening book
│       │   ├── engine_config.py # Configuration
│       │   ├── requirements.txt # Dependencies
│       │   └── tests/           # Test suite
│       └── book/                # Opening books (Polyglot)
│
└── prototypes/                  # Hardware prototypes
    ├── echiquier_8x8/           # Main 8×8 prototype
    │   ├── firmware/            # Embedded code
    │   │   ├── ia_embarquee/    # Game scripts
    │   │   │   ├── chess_game_v1.py
    │   │   │   └── chess_game_v2.py
    │   │   ├── vision/          # Camera detection (WIP)
    │   │   └── requirements.txt
    │   └── hardware/            # KiCad schematics
    │       ├── 8x8.kicad_sch
    │       └── 8x8.pdf
    └── echiquier_2x2/           # Test prototype (2×2)
```

---

## Getting Started

### Prerequisites

- Raspberry Pi 5 (8GB recommended) with Raspberry Pi OS 64-bit
- Python 3.10+ or PyPy3 for maximum performance
- Git

### Installation

```bash
# Clone the repository
git clone https://github.com/promaaa/smart-chess.git
cd smart-chess

# Navigate to the AI engine directory
cd ai/ia_marc/V2/

# Create a virtual environment
python3 -m venv venv
source venv/bin/activate

# Install dependencies
pip install -r requirements.txt
```

### Running the Game

```bash
# Navigate to the game scripts
cd prototypes/echiquier_8x8/firmware/ia_embarquee/

# Run the main game (V2 with menu)
python3 chess_game_v2.py
```

### Quick AI Test

```python
from ai.ia_marc.V2.engine_main import ChessEngine
import chess

# Create engine
engine = ChessEngine()

# Set difficulty
engine.set_level("Club")  # or engine.set_elo(1400)

# Get a move
board = chess.Board()
move = engine.get_move(board, time_limit=3.0)

print(f"Best move: {move}")
```

### Opening Book (Optional)

For stronger openings, download a Polyglot opening book:

```bash
# Create book directory
mkdir -p ai/ia_marc/book/

# Download a book (example: Cerebellum Light)
# Place the .bin file in ai/ia_marc/book/
```

---

## Documentation

### Technical References

| Document | Location | Description |
|---|---|---|
| Hardware Structure | `prototypes/echiquier_8x8/firmware/structure.md` | Full hardware documentation |
| AI Engine README | `ai/ia_marc/V2/README.md` | Detailed engine documentation |
| Hardware Schematic | `prototypes/echiquier_8x8/hardware/8x8.pdf` | KiCad schematic export |

### Key APIs

**ChessEngine (ai/ia_marc/V2/engine_main.py)**:
- `get_move(board, time_limit)`: Get best move for position
- `set_level(name)`: Set difficulty by name
- `set_elo(elo)`: Set difficulty by ELO (400-2400)
- `set_personality(name)`: Set playing style
- `get_move_with_stats(board)`: Get move with search statistics

### Future Improvements

- [ ] Camera-based piece recognition (computer vision)
- [ ] UCI protocol support for external GUI
- [ ] Web interface for remote play
- [ ] Neural network evaluation (planned)
- [ ] Endgame tablebases support

---

## Contributing

Contributions are welcome! To contribute:

1. Fork the repository
2. Create a feature branch (`git checkout -b feature/improvement`)
3. Commit your changes (`git commit -m 'Add new feature'`)
4. Push to the branch (`git push origin feature/improvement`)
5. Open a Pull Request

### Areas for Contribution

- Performance optimization of the search algorithm
- Adding tactical test positions
- Extending the opening book
- Improving position evaluation heuristics
- Hardware design improvements

---

## License

This project is licensed under the MIT License - see the [LICENSE](LICENSE) file for details.

---

## Acknowledgments

- [python-chess](https://python-chess.readthedocs.io/) - Chess library for Python
- [PeSTO](https://www.chessprogramming.org/PeSTO%27s_Evaluation_Function) - Piece-Square tables
- [Chess Programming Wiki](https://www.chessprogramming.org/) - Invaluable resource for chess programming techniques
- Adafruit libraries for hardware interfacing (HT16K33, MCP23017, TCA9548A)

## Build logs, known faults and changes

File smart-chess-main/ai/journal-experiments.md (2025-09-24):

# List of experiments and improvements added to the AI

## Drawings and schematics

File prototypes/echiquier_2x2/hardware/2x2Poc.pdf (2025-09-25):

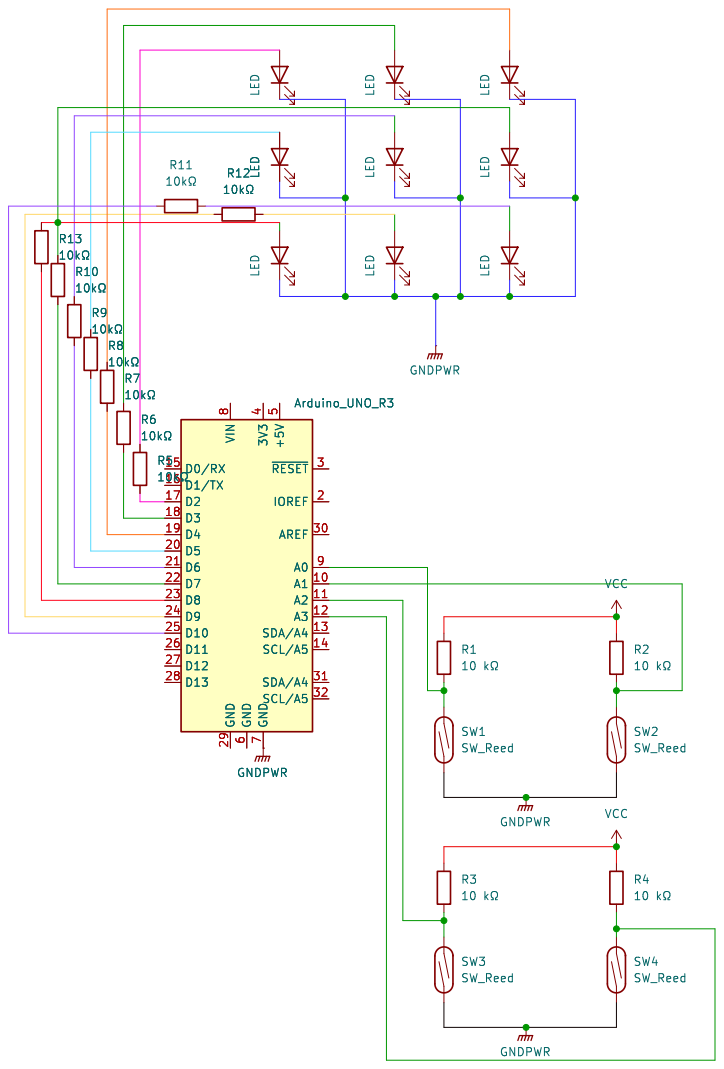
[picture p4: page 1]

Id: 1/1 Title: File: 2x2Poc.kicad_sch Sheet: / LED

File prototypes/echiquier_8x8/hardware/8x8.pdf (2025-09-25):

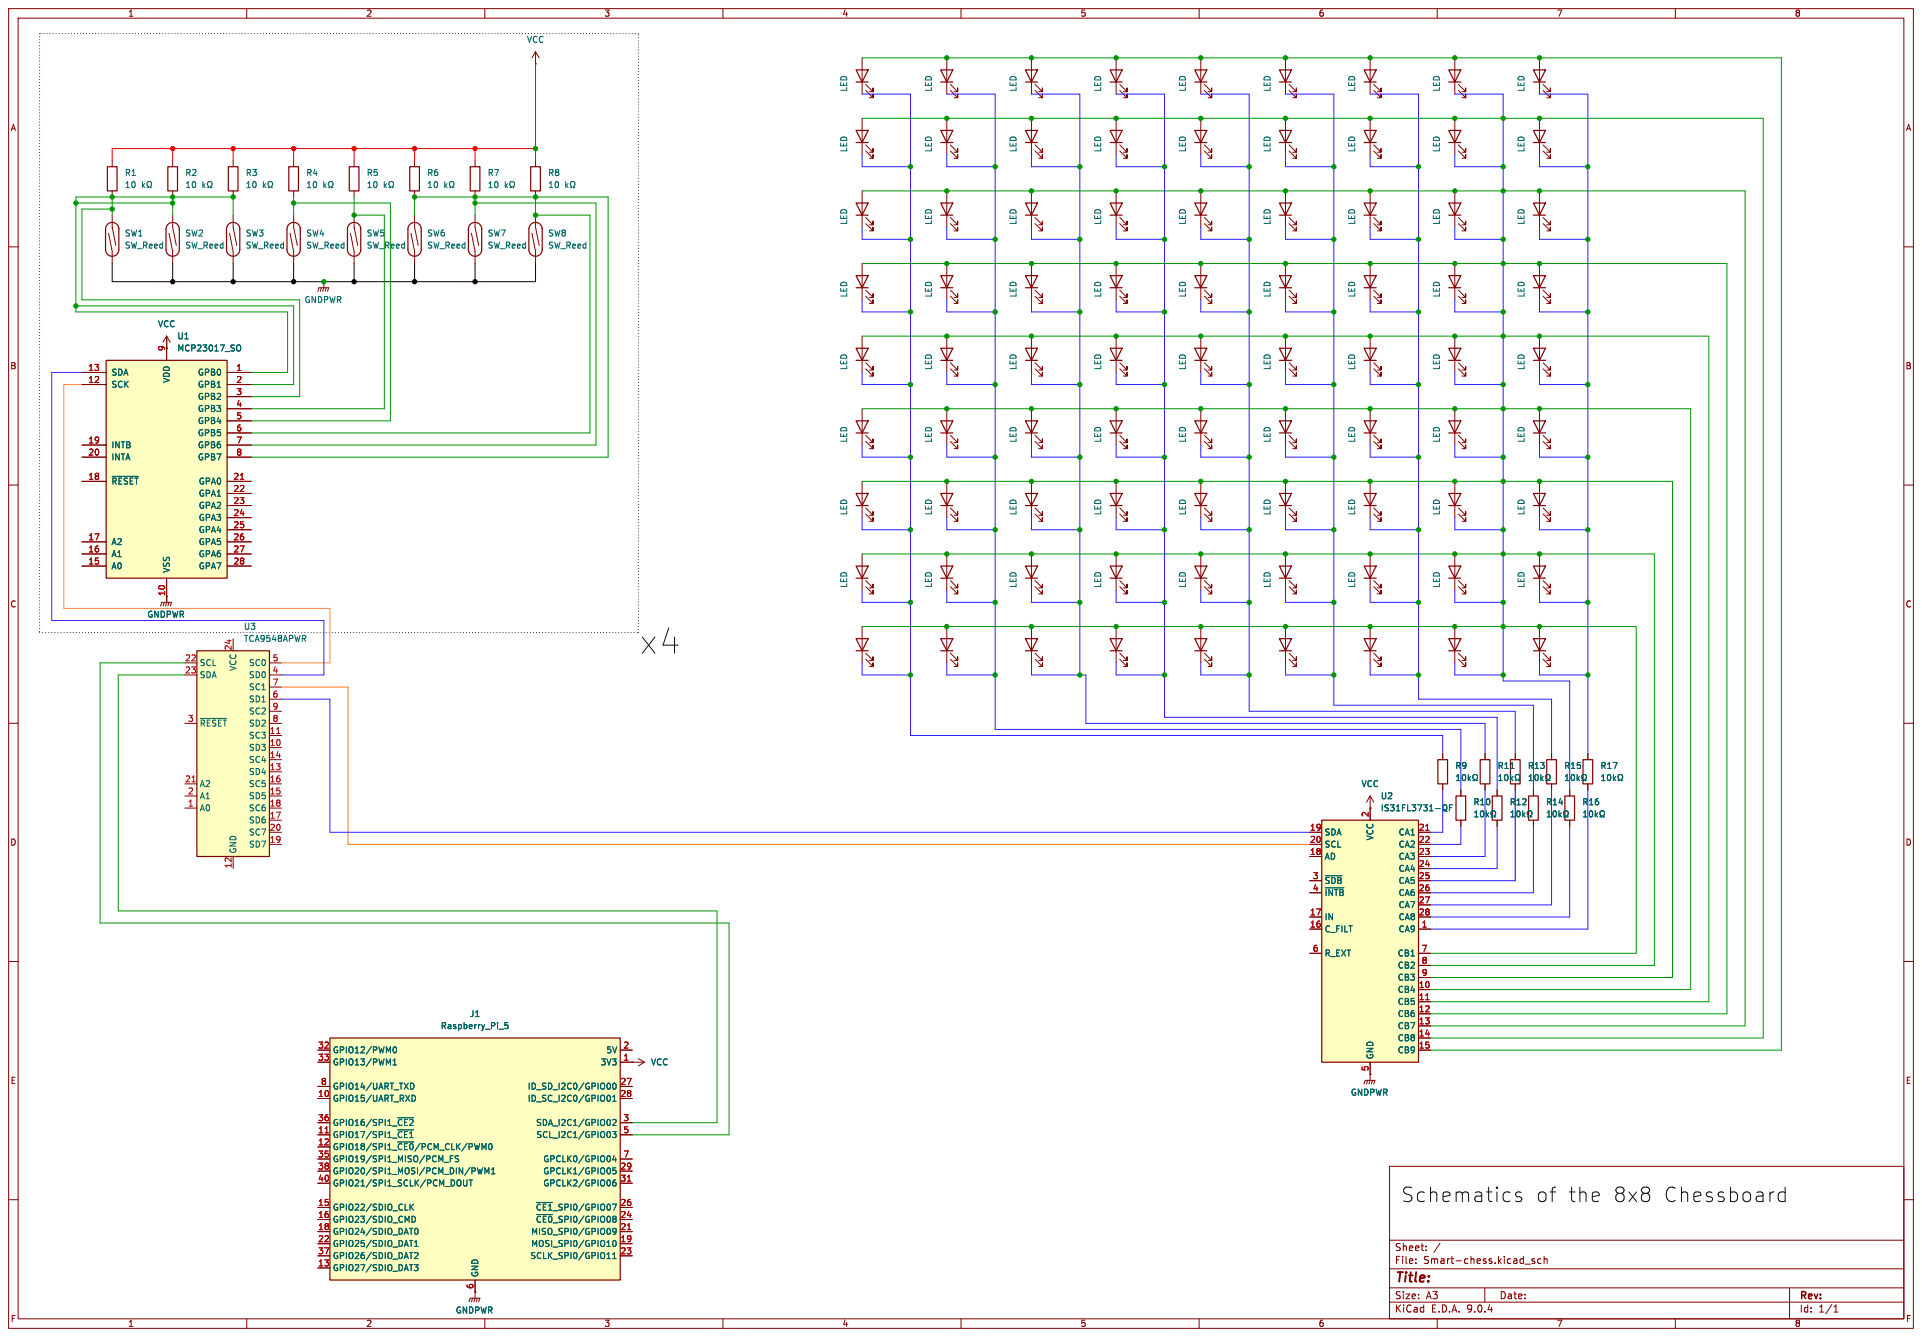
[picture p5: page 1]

IS31FL3731-QF SDA 19 SCL 20 AD 18 ~{SDB} 3 ~{INTB} 4
SDA 19 SCL 20 AD 18 ~{SDB} 3 ~{INTB} 4

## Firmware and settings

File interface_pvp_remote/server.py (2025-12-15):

#!/usr/bin/env python3
"""
Interface PvP Remote - Serveur WebSocket
Serveur combinant HTTP (fichiers statiques) et WebSocket (temps réel).
"""

import asyncio
import json
import os
import sys
import argparse
from http.server import HTTPServer, SimpleHTTPRequestHandler
from urllib.parse import urlparse
import threading
import time

# Ajouter le chemin pour python-chess
sys.path.insert(0, os.path.dirname(os.path.abspath(__file__)))

try:
    import websockets
except ImportError:
    print("Installation de websockets...")
    import subprocess
    subprocess.check_call([sys.executable, "-m", "pip", "install", "websockets"])
    import websockets

from hardware_bridge import HardwareBridge
from game_manager import GameManager, PlayerType


class PvPRemoteServer:
    """Serveur principal pour le jeu PvP à distance."""
    
    def __init__(self, http_port: int = 8081, ws_port: int = 8082, simulation: bool = False):
        self.http_port = http_port
        self.ws_port = ws_port
        self.simulation = simulation
        
        # Composants
        self.game = GameManager()
        self.hardware = HardwareBridge(simulation=simulation)
        
        # WebSocket clients
        self.clients: set = set()
        
        # État
        self.running = False
        
        # Configurer le callback pour les changements de capteurs
        self.hardware.set_state_change_callback(self._on_board_state_change)
    
    def _on_board_state_change(self, lifted, placed):
        """Callback appelé quand l'état du plateau change."""
        print(f"[Server] Changement détecté - lifted: {lifted}, placed: {placed}")
        
        # Vérifier que c'est le tour du joueur physique
        if self.game.get_current_player() != PlayerType.PHYSICAL:
            print("[Server] Ce n'est pas le tour du joueur physique, ignoré")
            return
        
        # Attendre la stabilisation
        time.sleep(0.5)
        
        # Détecter le coup
        move = self.game.detect_move_from_state_change(lifted, placed)
        
        if move:
            from_sq, to_sq = move
            print(f"[Server] Coup physique détecté: {from_sq} -> {to_sq}")
            
            # Valider et jouer le coup
            move_result = self.game.make_move(from_sq, to_sq)
            
            if move_result:
                # Illuminer le coup joué
                self.hardware.highlight_move(from_sq, to_sq)
                
                # Notifier tous les clients
                asyncio.run_coroutine_threadsafe(
                    self._broadcast({
                        "type": "physical_move",
                        "move": move_result,
                        "game_status": self.game.get_game_status()
                    }),
                    self.loop
                )
            else:
                print(f"[Server] Coup invalide: {from_sq} -> {to_sq}")
                asyncio.run_coroutine_threadsafe(
                    self._broadcast({
                        "type": "error",
                        "message": f"Coup illégal: {from_sq}-{to_sq}"
                    }),
                    self.loop
                )
    
    async def _broadcast(self, message: dict):
        """Envoie un message à tous les clients connectés."""
        if self.clients:
            msg = json.dumps(message)
            await asyncio.gather(
                *[client.send(msg) for client in self.clients],
                return_exceptions=True
            )
    
    async def _handle_websocket(self, websocket):
        """Gère une connexion WebSocket."""
        self.clients.add(websocket)
        client_addr = websocket.remote_address
        print(f"[WS] Client connecté: {client_addr}")
        
        try:
            # Envoyer l'état initial
            await websocket.send(json.dumps({
                "type": "init",
                "game_status": self.game.get_game_status(),
                "simulation": self.simulation
            }))
            
            async for message in websocket:
                await self._handle_message(websocket, message)
                
        except websockets.exceptions.ConnectionClosed:
            print(f"[WS] Client déconnecté: {client_addr}")
        finally:
            self.clients.discard(websocket)
    
    async def _handle_message(self, websocket, message: str):
        """Traite un message reçu d'un client."""
        try:
            data = json.loads(message)
            msg_type = data.get("type")
            
            if msg_type == "web_move":
                await self._handle_web_move(websocket, data)
            
            elif msg_type == "simulate_physical_move":
                await self._handle_simulate_physical_move(websocket, data)
            
            elif msg_type == "reset":
                await self._handle_reset(websocket)
            
            elif msg_type == "get_status":
                await websocket.send(json.dumps({
                    "type": "status",
                    "game_status": self.game.get_game_status()
                }))
            
            elif msg_type == "ping":
                await websocket.send(json.dumps({"type": "pong"}))
            
            else:
                print(f"[WS] Message inconnu: {msg_type}")
                
        except json.JSONDecodeError:
            print(f"[WS] Message invalide: {message}")
    
    async def _handle_web_move(self, websocket, data: dict):
        """Traite un coup du joueur web."""
        from_sq = data.get("from")
        to_sq = data.get("to")
        promotion = data.get("promotion")
        
        print(f"[Server] Coup web reçu: {from_sq} -> {to_sq}")
        
        # Vérifier que c'est le tour du joueur web
        if self.game.get_current_player() != PlayerType.WEB:
            await websocket.send(json.dumps({
                "type": "error",
                "message": "Ce n'est pas votre tour"
            }))
            return
        
        # Jouer le coup
        move_result = self.game.make_move(from_sq, to_sq, promotion)
        
        if move_result:
            # Illuminer le coup sur le plateau physique
            self.hardware.highlight_move(from_sq, to_sq)
            
            # Notifier tous les clients
            await self._broadcast({
                "type": "web_move",
                "move": move_result,
                "game_status": self.game.get_game_status()
            })
        else:
            await websocket.send(json.dumps({
                "type": "error",
                "message": f"Coup illégal: {from_sq}-{to_sq}"
            }))
    
    async def _handle_simulate_physical_move(self, websocket, data: dict):
        """Simule un coup du joueur physique (mode simulation uniquement)."""
        if not self.simulation:
            await websocket.send(json.dumps({
                "type": "error",
                "message": "Simulation désactivée"
            }))
            return
        
        from_sq = data.get("from")
        to_sq = data.get("to")
        
        print(f"[Server] Simulation coup physique: {from_sq} -> {to_sq}")
        
        # Vérifier que c'est le tour du joueur physique
        if self.game.get_current_player() != PlayerType.PHYSICAL:
            await websocket.send(json.dumps({
                "type": "error",
                "message": "Ce n'est pas le tour du joueur physique"
            }))
            return
        
        # Jouer le coup
        move_result = self.game.make_move(from_sq, to_sq)
        
        if move_result:
            # Simuler le déplacement sur le plateau
            self.hardware.simulate_move(from_sq, to_sq)
            self.hardware.highlight_move(from_sq, to_sq)
            
            # Notifier tous les clients
            await self._broadcast({
                "type": "physical_move",
                "move": move_result,
                "game_status": self.game.get_game_status()
            })
        else:
            await websocket.send(json.dumps({
                "type": "error",
                "message": f"Coup illégal: {from_sq}-{to_sq}"
            }))
    
    async def _handle_reset(self, websocket):
        """Réinitialise la partie."""
        print("[Server] Réinitialisation de la partie")
        self.game.reset()
        self.hardware.clear_all_leds()
        
        await self._broadcast({
            "type": "reset",
            "game_status": self.game.get_game_status()
        })
    
    def _run_http_server(self):
        """Lance le serveur HTTP dans un thread séparé."""
        os.chdir(os.path.dirname(os.path.abspath(__file__)))
        
        handler = SimpleHTTPRequestHandler
        httpd = HTTPServer(('', self.http_port), handler)
        print(f"[HTTP] Serveur démarré sur http://localhost:{self.http_port}")
        
        while self.running:
            httpd.handle_request()
    
    async def start(self):
        """Démarre le serveur."""
        self.running = True
        self.loop = asyncio.get_event_loop()
        
        # Démarrer le polling des capteurs
        self.hardware.start_polling(interval=0.1)
        
        # Démarrer le serveur HTTP dans un thread
        http_thread = threading.Thread(target=self._run_http_server, daemon=True)
        http_thread.start()
        
        # Démarrer le serveur WebSocket
        print(f"[WS] Serveur démarré sur ws://localhost:{self.ws_port}")
        
        print("\n" + "=" * 60)
        print("Interface PvP Remote - Serveur démarré")
        print(f"  Interface Web: http://localhost:{self.http_port}")
        print(f"  WebSocket:     ws://localhost:{self.ws_port}")
        print(f"  Mode:          {'SIMULATION' if self.simulation else 'HARDWARE'}")
        print("=" * 60 + "\n")
        
        async with websockets.serve(self._handle_websocket, "", self.ws_port):
            await asyncio.Future()  # Run forever
    
    def stop(self):
        """Arrête le serveur."""
        self.running = False
        self.hardware.cleanup()
        print("[Server] Arrêt du serveur")


def main():
    parser = argparse.ArgumentParser(description='Interface PvP Remote Server')
    parser.add_argument('--http-port', type=int, default=8081, help='Port HTTP')
    parser.add_argument('--ws-port', type=int, default=8082, help='Port WebSocket')
    parser.add_argument('--simulation', '-s', action='store_true', help='Mode simulation')
    args = parser.parse_args()
    
    server = PvPRemoteServer(
        http_port=args.http_port,
        ws_port=args.ws_port,
        simulation=args.simulation
    )
    
    try:
        asyncio.run(server.start())
    except KeyboardInterrupt:
        print("\n[Server] Interruption par l'utilisateur")
        server.stop()


if __name__ == "__main__":
    main()

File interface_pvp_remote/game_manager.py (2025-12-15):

#!/usr/bin/env python3
"""
Interface PvP Remote - Game Manager
Gestion de l'état de la partie d'échecs.
"""

import chess
from typing import Optional, Tuple, List, Dict, Any
from enum import Enum


class PlayerType(Enum):
    """Type de joueur."""
    WEB = "web"
    PHYSICAL = "physical"


class GameManager:
    """Gestionnaire de l'état de la partie."""
    
    def __init__(self):
        self.board = chess.Board()
        self.move_history: List[Dict[str, Any]] = []
        
        # Configuration des joueurs
        self.web_color = chess.WHITE  # Le joueur web joue les blancs
        self.physical_color = chess.BLACK  # Le joueur physique joue les noirs
        
        # État
        self.waiting_for_physical_confirmation = False
        self.pending_move: Optional[chess.Move] = None
    
    def reset(self):
        """Réinitialise la partie."""
        self.board = chess.Board()
        self.move_history = []
        self.waiting_for_physical_confirmation = False
        self.pending_move = None
    
    def get_current_player(self) -> PlayerType:
        """Retourne le type de joueur dont c'est le tour."""
        if self.board.turn == self.web_color:
            return PlayerType.WEB
        return PlayerType.PHYSICAL
    
    def get_fen(self) -> str:
        """Retourne le FEN actuel."""
        return self.board.fen()
    
    def get_legal_moves(self) -> List[str]:
        """Retourne la liste des coups légaux en UCI."""
        return [move.uci() for move in self.board.legal_moves]
    
    def is_legal_move(self, from_sq: str, to_sq: str, promotion: str = None) -> bool:
        """Vérifie si un coup est légal."""
        try:
            uci = from_sq + to_sq
            if promotion:
                uci += promotion
            move = chess.Move.from_uci(uci)
            return move in self.board.legal_moves
        except:
            return False
    
    def make_move(self, from_sq: str, to_sq: str, promotion: str = None) -> Optional[Dict[str, Any]]:
        """
        Effectue un coup et retourne les informations du coup.
        Retourne None si le coup est illégal.
        """
        try:
            uci = from_sq + to_sq
            if promotion:
                uci += promotion
            
            move = chess.Move.from_uci(uci)
            
            if move not in self.board.legal_moves:
                # Vérifier si c'est une promotion manquante
                for legal in self.board.legal_moves:
                    if legal.from_square == move.from_square and legal.to_square == move.to_square:
                        if legal.promotion:
                            move = legal  # Utiliser la promotion par défaut (dame)
                            break
                else:
                    return None
            
            # Informations avant le coup
            san = self.board.san(move)
            is_capture = self.board.is_capture(move)
            is_check = False
            is_checkmate = False
            is_castling = self.board.is_castling(move)
            
            # Jouer le coup
            self.board.push(move)
            
            # Informations après le coup
            is_check = self.board.is_check()
            is_checkmate = self.board.is_checkmate()
            is_stalemate = self.board.is_stalemate()
            is_game_over = self.board.is_game_over()
            
            move_info = {
                "from": from_sq,
                "to": to_sq,
                "san": san,
                "uci": move.uci(),
                "promotion": chess.piece_symbol(move.promotion).lower() if move.promotion else None,
                "is_capture": is_capture,
                "is_check": is_check,
                "is_checkmate": is_checkmate,
                "is_castling": is_castling,
                "is_stalemate": is_stalemate,
                "is_game_over": is_game_over,
                "fen": self.board.fen(),
                "move_number": len(self.move_history) + 1
            }
            
            self.move_history.append(move_info)
            
            return move_info
            
        except Exception as e:
            print(f"[GameManager] Erreur make_move: {e}")
            return None
    
    def detect_move_from_state_change(
        self, 
        lifted: List[Tuple[int, int]], 
        placed: List[Tuple[int, int]]
    ) -> Optional[Tuple[str, str]]:
        """
        Détecte un coup à partir des changements d'état du plateau.
        Retourne (from_square, to_square) ou None si invalide.
        """
        # Mouvement simple: 1 pièce soulevée, 1 pièce posée
        if len(lifted) == 1 and len(placed) == 1:
            from_row, from_col = lifted[0]
            to_row, to_col = placed[0]
            from_sq = self._coords_to_square(from_row, from_col)
            to_sq = self._coords_to_square(to_row, to_col)
            return (from_sq, to_sq)
        
        # Capture: 2 pièces soulevées, 1 pièce posée
        if len(lifted) == 2 and len(placed) == 1:
            to_row, to_col = placed[0]
            to_sq = self._coords_to_square(to_row, to_col)
            
            # Trouver la case de départ (celle qui n'est pas la case d'arrivée)
            for row, col in lifted:
                if (row, col) != (to_row, to_col):
                    from_sq = self._coords_to_square(row, col)
                    return (from_sq, to_sq)
        
        # Roque: 2 pièces soulevées, 2 pièces posées
        if len(lifted) == 2 and len(placed) == 2:
            king_sq = self.board.king(self.board.turn)
            if king_sq is not None:
                king_row = chess.square_rank(king_sq)
                king_col = chess.square_file(king_sq)
                
                for row, col in lifted:
                    if row == king_row and col == king_col:
                        # Le roi a été soulevé, chercher sa destination
                        for pr, pc in placed:
                            if pr == king_row and (pc == 2 or pc == 6):  # c ou g file
                                from_sq = self._coords_to_square(king_row, king_col)
                                to_sq = self._coords_to_square(pr, pc)
                                return (from_sq, to_sq)
        
        return None
    
    def _coords_to_square(self, row: int, col: int) -> str:
        """Convertit des coordonnées (row, col) en notation algébrique."""
        file_char = chr(ord('a') + col)
        rank_char = str(row + 1)
        return file_char + rank_char
    
    def _square_to_coords(self, square: str) -> Tuple[int, int]:
        """Convertit une notation algébrique en coordonnées (row, col)."""
        col = ord(square[0]) - ord('a')
        row = int(square[1]) - 1
        return (row, col)
    
    def get_expected_board_state(self) -> List[List[bool]]:
        """
        Retourne l'état attendu du plateau physique basé sur la position actuelle.
        """
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

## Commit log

2025-09-24 second commit
    [Smart-chess.kicad_sch]
2025-09-24 correct renaming
    [8x8.kicad_sch]
2025-09-25 Modified schematics
    [2x2Poc.kicad_sch, 8x8.kicad_sch]
2025-10-02 coorection boucle infini lors du test de la légalité d'un roque
2025-10-02 séparation des IA en plusieurs fichiers
2025-10-02 ajout d'une IA avec table de transposition
2025-10-02 ajout cut aléatoire
2025-10-13 amélioration de la gestion des bitboards
    [2x2Poc.kicad_sch, 8x8.kicad_sch]
2025-10-14 Restructuration du repo
    [2x2Poc.kicad_sch, 8x8.kicad_sch]
2025-10-18 Tests for 8x8 prototype, detection and requirements
2025-10-18 feat(training): add LR warmup, global LeakyReLU, LR scheduler; increase capacity to 256x256; dataset sampling to 200k; improved epoch metrics output; add dataset/hardware diagnostics and docs
2025-10-18 Fix: Persistance des moments Adam + ré-échantillonnage par epoch
    Changements majeurs:
    - Fix critique: Sauvegarde/chargement des moments Adam pour continuité optimisation
    - Ré-échantillonnage du dataset à chaque epoch (20x plus de données uniques)
    - Warm-start du biais seulement pour nouveaux réseaux
    - Détection automatique nouveau réseau vs réseau chargé
    Nouveaux fichiers:
    - FIX_ADAM_PERSISTENCE.md: Documentation du fix Adam
    - test_adam_persistence.py: Test validation persistance Adam
    - test_generalization.py: Test généralisation sur différents échantillons
    - check_weights_persistence.py: Diagnostic persistance poids
    - visualize_sampling.py: Visualisation impact ré-échanti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
2025-10-26 Créé à l'aide de Colab
2025-10-26 enregistrement des nouveaux poids dans drive
2025-10-27 augmentation de la taille des hidden layers (256 à 512)
    [smoke_extended_summary.csv]
2025-11-02 beaucoup mieux en fin de parti
2025-11-15 ajout de la structure
2025-11-16 paramètre optimisé stagne autour d'un rmse de 0.35
2025-11-16 réseau de convolution
    utilise les réseaux de convolution mais pour l'instant les résultats ne sont vraiment pas satisfaisant
2025-11-18 Update de l'algo de recherche
2025-11-18 Implémentation de l'IA-Marc V2 : Moteur de recherche avancé (PVS, TT, Move Ordering) et intégration matérielle
2025-11-20 feat: Implement 9 difficulty levels and enhance AI engine
    Implement 9 adjustable difficulty levels (200 ELO to 1800 ELO) for the AI,
    along with a new menu-driven version of chess_game_IA.py to allow user selection.
    Key improvements and refactorings:
    - Implemented 9 distinct difficulty levels with tailored search parameters, time limits, and error rates.
    - Enhanced evaluation function with weighted mobility, improved king safety evaluation, and finer-grained pawn structure analysis.
    - Upgraded the search algorithm to a full-featured PVS (Principal Variation Search) with Iterative Deepening, Aspiration Windows, Null Move Pruning, and Late Move Reduction.
    - Improved engine stability and perfor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
    [chess_game_IA.py]
2025-11-20 Restructuration et amélioration massive de ia_marc
    [2x2Poc.kicad_sch, 8x8.kicad_sch]
2025-11-20 feat(ia-marc): Implement 10 advanced search optimizations (+320-520 ELO)
    - Phase 1: IIR, RFP, Check/Pawn Extensions (+110-200 ELO)
    - Phase 2: Futility Pruning, Late Move Pruning (+100-150 ELO)
    - Phase 3: 4-slot Killers, Continuation History, SEE (+80-120 ELO)
    - Phase 4: Soft/Hard Time Bounds (+30-50 ELO)
    Techniques inspired by Tiny Chess Bot champions (BoyChesser, TinyHugeBot, NNBot).
    All UCI tests passing. Optimized for Raspberry Pi 5 8GB.
    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
2025-11-23 Modifications programme de fonctionnement échec
2025-11-24 Create compared
    pour comparé plusieurs main engine (ici ia de marc vs la dernière version de notre ia)
2025-11-30 utilise pythran
    mais pour l'instant les résultats ne sont vraiment pas bon
2025-11-30 convertion en entier
    donne des bons résultats (contre stockfish level 3 environs 4 victoirs gagné sur 10)
2025-12-03 supporte plus de profondeur et nouvelle ouverture
2025-12-14 Add files via upload
    pour tester les différents niveau automatiquements
2025-12-14 Add files via upload
    pour définir les différents niveau
2025-12-14 Add files via upload
    pour affronter des niveaux / différentes version ensembles
2025-12-15 deleted plein de trucs
    [smoke_extended_summary.csv]
2025-12-15 supprimé tous les fichiers obsolètes
2025-12-17 Calcul de la complexité de ChessInteractif14.py
2025-12-17 Tournoi entre tous les niveaux
    But: Vérifié si la définition des niveaux est cohérentes en match réel
2025-12-17 Match stockfish-moteur
    évaluer la performence du moteur
2025-12-18 Evaluation numérique des position d'échecs
    à partir de: matériel, placement des pièces et règles stratégiques
2025-12-18 version 14 du moteur d'échec (la plus performante)
2025-12-18 version 16 (version 14 + ouverture)
    ouverture importé d'internet il faut télécharger OPTIMUS32.bin
2026-10-06 Rework README around the teaser GIF and the KiCad schematic
    - Add the teaser GIF at the top, linked to the retrospective video
    - Show the KiCad 8x8 schematic (white background for dark mode)
    - Add build photos: gantry CAD, reed switches, finished board
    - Shorten the README: highlights, how it works, hardware, AI, quick start
2026-10-06 Compress the teaser GIF, add the LED test GIF and remove the roadmap
    - Teaser GIF: 27.9 MB -> 7.0 MB (800 px, 16 fps), first dark second cut
    - Replace the reed photo with a GIF of the wiring during an LED test
    - Crop the finished board photo on the logo and screen side
    - Remove the roadmap section
2026-10-06 Show real-time piece detection and the lower wiring in the build table
    - Replace the finished board photo with the piece detection GIF
    - Crop the LED test GIF lower, on the bottom rows and expander boards
2026-10-06 Rework the build gallery: side view on top, two GIFs below
    - Replace the gantry CAD image with the side view of the finished board
    - Use a two-column layout so the images are larger
    - Crop the LED test GIF a bit higher
